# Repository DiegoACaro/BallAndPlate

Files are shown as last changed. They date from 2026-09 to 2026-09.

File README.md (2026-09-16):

# Ball and Plate — Control Systems Comparison

> Experimental Ball and Plate platform for comparing classical, modern, and biologically inspired control strategies.





<p align="center">
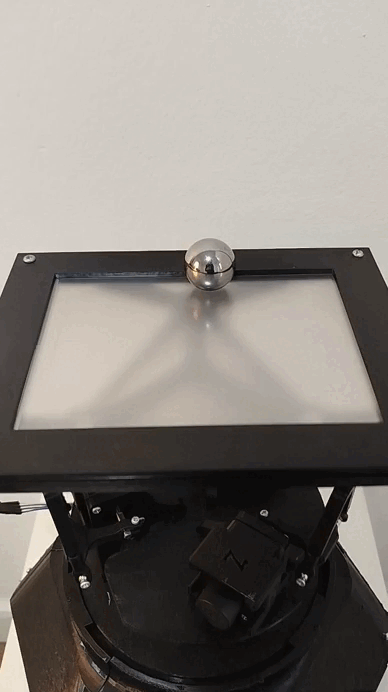
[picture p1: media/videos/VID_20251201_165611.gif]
Ball and Plate platform demo
  
</p>

## Overview

This project presents the design and experimental implementation of a **Ball and Plate system** developed as a platform for studying and comparing different control approaches.

The system consists of a mobile platform whose inclination is controlled to regulate the position of a ball on its surface. Because the plant is nonlinear and inherently unstable, the platform provides a practical testbed for evaluating controller performance under real physical conditions.

The project was developed as an undergraduate Mechatronics Engineering thesis at **Universidad Autónoma de Occidente** in 2025.

The study compares:

- **PID control**
- **Discrete LQR control with integral action**
- **Biologically inspired neural-network-based control**

The experimental evaluation considers parameters such as settling time, overshoot, position regulation, stability, and response to different reference trajectories.

## Project Objectives

The main objective was to design and implement a Ball and Plate system to compare modern control algorithms with biologically inspired neural networks.

The project included:

1. Designing and constructing the physical Ball and Plate platform.
2. Implementing the sensing, processing, actuation, and communication subsystems.
3. Developing a mathematical model of the system.
4. Implementing a classical PID controller.
5. Designing and implementing a discrete LQR controller.
6. Developing a biologically inspired sensoriomotor neural architecture.
7. Experimentally evaluating and comparing the controllers.

## System Architecture

The complete system integrates:

```text
                ┌──────────────────────┐
                │      Ball Position   │
                │        Sensing        │
                └──────────┬───────────┘
                           │
                           ▼
                ┌──────────────────────┐
                │  Embedded Processing │
                │        ESP32         │
                └──────────┬───────────┘
                           │
             ┌─────────────┼─────────────┐
             │             │             │
             ▼             ▼             ▼
          PID            LQR        Neural Control
             │             │             │
             └─────────────┼─────────────┘
                           │
                           ▼
                ┌──────────────────────┐
                │      Actuators       │
                └──────────┬───────────┘
                           │
                           ▼
                ┌──────────────────────┐
                │    Mobile Platform   │
                │     Ball & Plate     │
                └──────────────────────┘
```

## Mechanical Design

The platform was designed as a **3RRS parallel mechanism**, inspired by the kinematic principles of Stewart platforms.

The thesis explicitly treats the system as a simplified parallel mechanism rather than a full six-degree-of-freedom Stewart platform.

The mechanical development included:

- Fixed base
- Mobile platform
- Actuator mounting brackets
- Motor arms
- Passive links
- Spherical joints
- Structural enclosure
- 3D-printed components
- Complete mechanical assembly

The design process included CAD modeling, material selection, manufacturing considerations, and physical assembly.

## Mathematical Modeling

A mathematical model was developed to describe the dynamics of the Ball and Plate system.

The modeling process included:

- Definition of coordinate systems and state variables
- Kinematic relationships
- Kinetic-energy analysis
- Potential-energy analysis
- System equations
- Linearization around the equilibrium point
- Actuator modeling
- Inverse kinematics

The linearized model was subsequently used for the modern control design.

## Control Strategies

### 1. PID Controller

A PID controller was implemented as a classical control baseline.

The proportional, integral, and derivative gains were adjusted heuristically to obtain a stable response suitable for experimental operation.

The PID controller was used as an accessible baseline for evaluating the more advanced approaches.

### 2. Discrete LQR Controller

A discrete Linear Quadratic Regulator was designed using the linearized system model.

The controller incorporates integral action to reduce steady-state error for non-zero references.

The design process included:

- State-space modeling
- System augmentation with an integral state
- Selection of weighting matrices using Bryson's rule
- Zero-Order Hold discretization
- Discrete controller implementation

The experimentally obtained gain parameters reported in the thesis include:

```text
Kp = [0.3717249833, 0.6492662298, 4.7860201182, 3.0881250565]
Ki = -0.0989469993
```

### 3. Biologically Inspired Neural Controller

The project also implements a biologically inspired sensoriomotor controller.

Its architecture is based on concepts inspired by biological visuomotor pathways and sensoriomotor transformations.

The network incorporates:

- Spatial coding
- Auxiliary neural layers
- Internal neuronal dynamics
- Activation conversion
- Modular organization
- Recurrent inhibitory interactions
- Motor neurons

The neural activity changes according to the position and movement of the ball. The auxiliary layers exhibit stronger activation when the ball is far from the center and lower activation as the ball approaches the desired equilibrium.

## Experimental Results

The controllers were experimentally evaluated using the physical Ball and Plate system.

The thesis reports the following measurements for the LQR and biologically inspired neural controllers:

| Controller | Axis | Maximum Position (m) | Overshoot | Settling Time |
|---|---:|---:|---:|---:|
| Neural | X | 0.145754 | 34.89% | 9.829 s |
| Neural | Y | 0.132814 | 36.17% | 9.703 s |
| Discrete LQR | X | 0.166377 | 44.32% | 7.961 s |
| Discrete LQR | Y | 0.121640 | 29.13% | 7.212 s |

The experiments also included reference trajectories with different geometries, including:

- Ellipse
- Square
- Infinity-shaped trajectory

The reported experimental results show that the discrete LQR achieved shorter settling times, while the biologically inspired controller exhibited lower overshoot on the X axis.

### Trajectory Tracking Gallery

For each reference trajectory, the platform's video response is shown alongside the tracked ball trajectory.

| Ellipse | Square | Infinity |
|:---:|:---:|:---:|
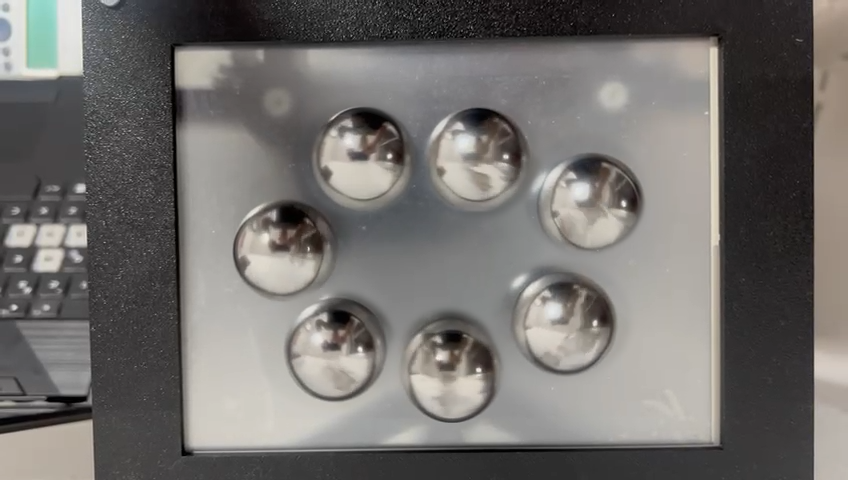
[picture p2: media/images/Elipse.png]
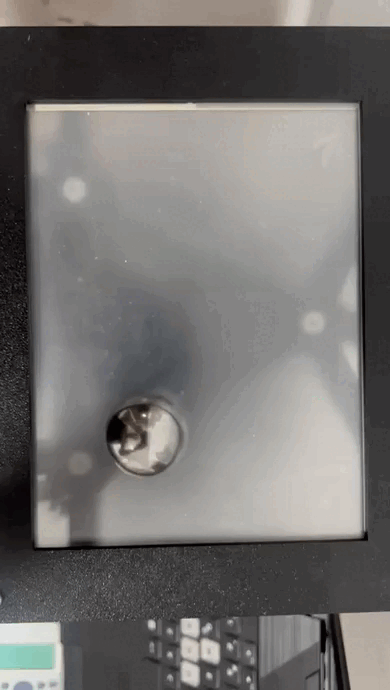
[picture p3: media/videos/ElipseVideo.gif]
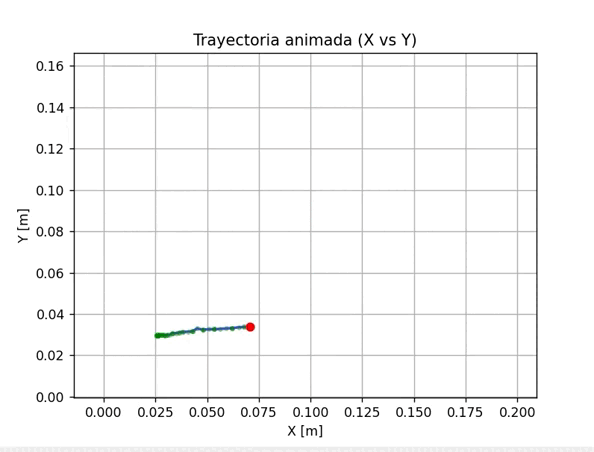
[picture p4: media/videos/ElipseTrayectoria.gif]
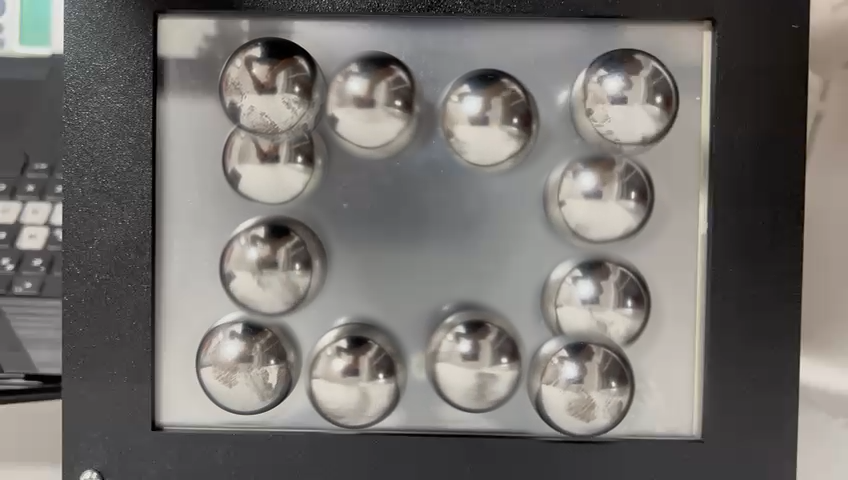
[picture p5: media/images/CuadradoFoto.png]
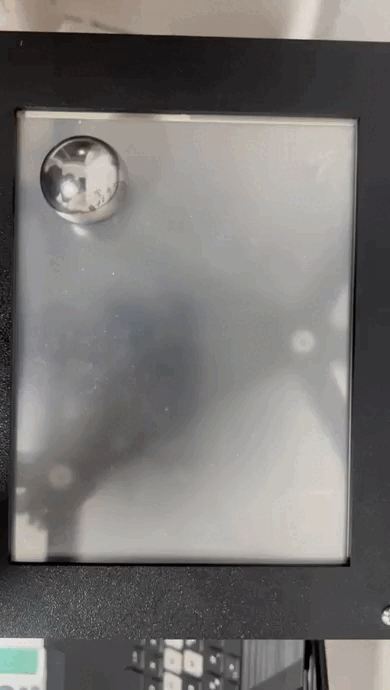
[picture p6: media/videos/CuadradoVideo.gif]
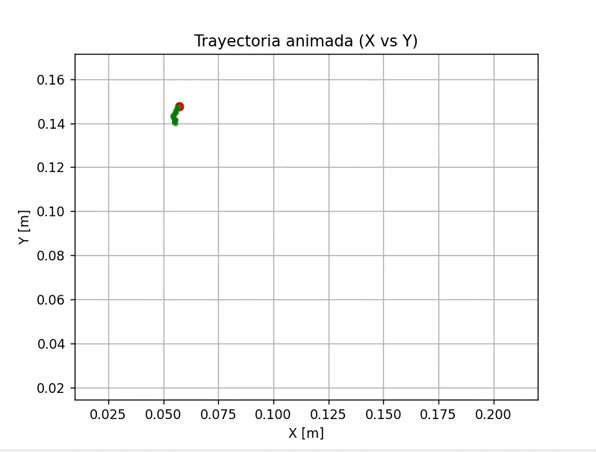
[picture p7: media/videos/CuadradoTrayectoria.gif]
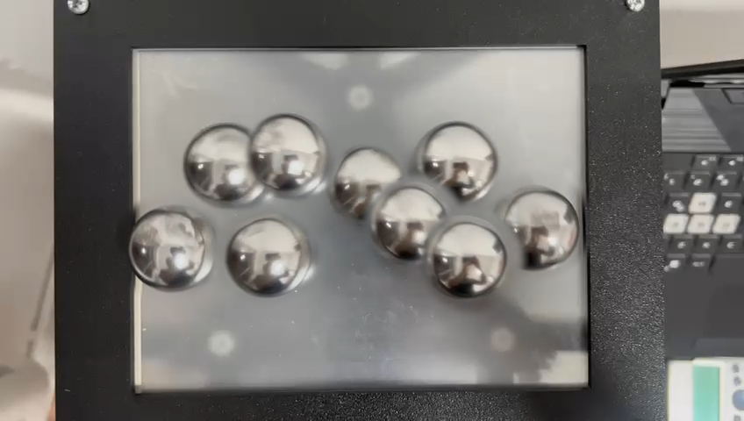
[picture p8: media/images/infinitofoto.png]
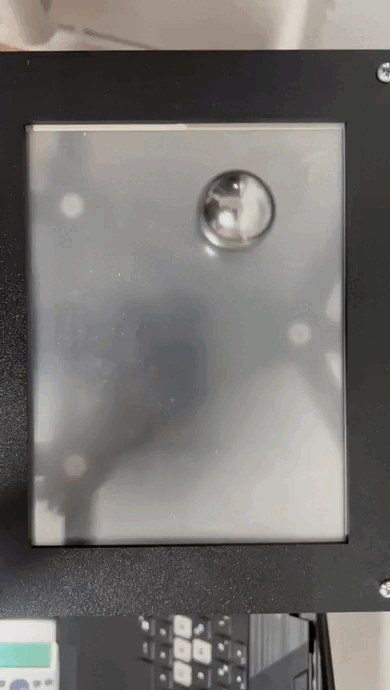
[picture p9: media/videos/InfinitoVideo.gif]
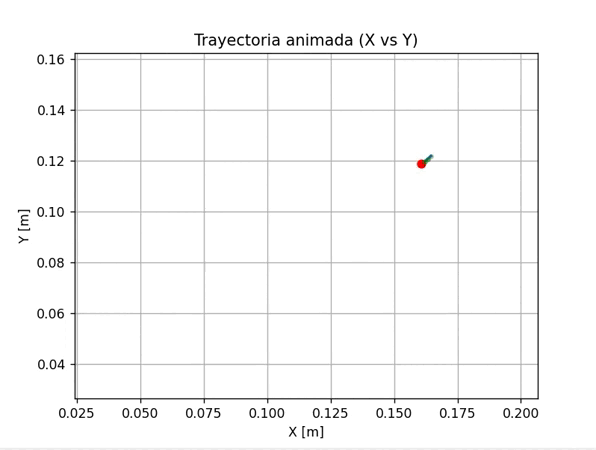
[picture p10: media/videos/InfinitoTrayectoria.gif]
| <br><br> | <br><br> | <br><br> |

*Top: reference setup photo · Middle: platform response video · Bottom: recorded ball trajectory*

### Controller Demonstrations

| Neural Controller | Follower / Tracking Demo |
|:---:|:---:|
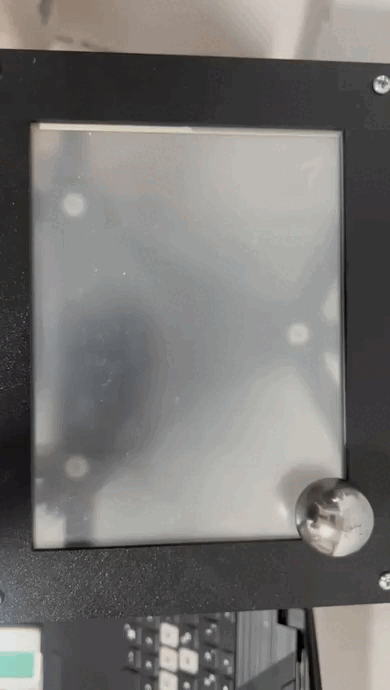
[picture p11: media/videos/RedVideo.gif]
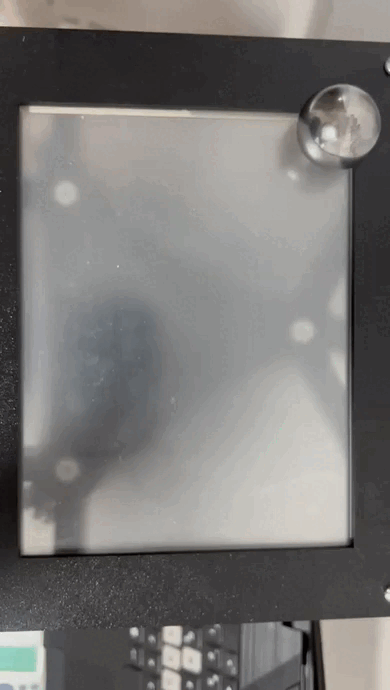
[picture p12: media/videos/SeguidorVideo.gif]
|  |  |

## Technologies

### Control & Modeling

- MATLAB
- State-space modeling
- PID control
- Discrete LQR / LQI
- Linearization
- Inverse kinematics

### Embedded Systems

- ESP32
- Arduino ecosystem
- Real-time control
- Sensor acquisition
- Actuator control
- Digital communication

### Mechanical Design

- SolidWorks
- CAD modeling
- Parallel mechanisms
- 3D-printed components
- Mechanical assembly

### Neural Control

- Biologically inspired neural networks
- Sensoriomotor transformations
- Recurrent inhibition
- Modular neural architectures

## Hardware

The thesis documents the selection and integration of:

- Camera-based ball-position sensing
- ESP32-based processing
- Actuators for platform inclination
- Electronic control hardware
- Mechanical links and spherical joints
- Custom-designed structural components

Component selection was performed through comparative screening matrices considering technical, operational, and economic criteria.

## Communication and Software

The system includes communication between the sensing, processing, control, and actuation subsystems.

The thesis also documents a graphical user interface (GUI) for interaction with the system and visualization of relevant information.

## Repository Structure

```text
ball-and-plate/
│
├── README.md
├── docs/
│   ├── thesis.pdf
│   ├── electronics/
│   └── diagrams/
│
├── cad/
│   ├── parts/
│   └── assembly/
│
├── src/
│
├── modeling/
│   ├── dynamics/
│   └── kinematics/
│
└── media/
    ├── images/
    └── videos/

```

> The structure above is a recommended organization for the repository. It should be adjusted to match the actual files included in the project.

## Key Engineering Topics

This project combines several areas of mechatronics and robotics:

- Control engineering
- State-space systems
- Optimal control
- Nonlinear-system analysis
- Parallel mechanisms
- Robot kinematics
- Embedded systems
- Computer vision
- Neural computation
- CAD and mechanical design
- Experimental validation

## Thesis

**Comparison of Modern Control and Biologically Inspired Neural Networks in the Implementation and Design of a Ball and Plate System**

**Authors:** Diego Alejandro Caro Vaca and Brian Steven Realpe Meneses  
**Program:** Mechatronics Engineering  
**Institution:** Universidad Autónoma de Occidente  
**Year:** 2025

The complete thesis contains the detailed mechanical design, component selection, mathematical modeling, controller design, neural architecture, experimental methodology, and results.

## Project Highlights

- Physical implementation of a Ball and Plate platform.
- 3RRS parallel mechanism.
- Mathematical modeling and linearization.
- Classical PID control.
- Discrete LQR with integral action.
- Biologically inspired sensoriomotor neural control.
- Experimental comparison using settling time and overshoot.
- Reference trajectory tracking.
- Integration of mechanical, electronic, sensing, and control subsystems.

## Authors

**Diego Alejandro Caro Vaca**  
Mechatronics Engineering

**Brian Steven Realpe Meneses**  
Mechatronics Engineering

---

*This repository documents an academic engineering project developed as part of a Mechatronics Engineering thesis.*

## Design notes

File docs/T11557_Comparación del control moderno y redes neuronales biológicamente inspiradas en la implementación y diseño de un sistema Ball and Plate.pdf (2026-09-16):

COMPARACIÓN DEL CONTROL MODERNO Y REDES NEURONALES BIOLÓGICAMENTE INSPIRADAS EN LA IMPLEMENTACIÓN Y DISEÑO DE UN SISTEMA BALL AND PLATE

DIEGO ALEJANDRO CARO VACA
2215332
BRIAN STEVEN REALPE MENESES 2190733

UNIVERSIDAD AUTÓNOMA DE OCCIDENTE FACULTAD DE INGENIERÍA Y CIECIAS BÁSICAS PROGRAMA INGENIERÍA MECATRÓNICA SANTIAGO DE CALI
2025

COMPARACIÓN DEL CONTROL MODERNO Y REDES NEURONALES BIOLÓGICAMENTE INSPIRADAS EN LA IMPLEMENTACIÓN Y DISEÑO DE UN SISTEMA BALL AND PLATE

DIEGO ALEJANDRO CARO VACA
BRIAN STEVEN REALPE MENESES

Proyecto de grado para optar al título de Ingeniero Mecatrónico

Director
JIMMY TOMBE ANDRADE
Ingeniero Eléctrico
Magíster en Ingeniería

UNIVERSIDAD AUTÓNOMA DE OCCIDENTE FACULTAD DE INGENIERÍA Y CIECIAS BÁSICAS PROGRAMA INGENIERÍA MECATRÓNICA SANTIAGO DE CALI
2025

Nota de aceptación:

Aprobado por el Comité de Grado en cumplimiento de los requisitos exigidos
por | la | Universidad | Autónoma | de
Occidente para optar al título de Ingeniero Mecatrónico

DAVID FERNANDO RAMÍREZ MORENO Jurado

Santiago de Cali, 04 de diciembre de 2025

"Este trabajo refleja el valor de la constancia y la perseverancia frente a los desafíos, recordando que el esfuerzo continuo siempre conduce a resultados."
Dedicado a mis padres, Lisbeth Vaca y Diego Alexander Caro, en agradecimiento por su amor incondicional, por enseñarme el valor del esfuerzo y la constancia y por el apoyo que me han brindado a lo largo de mi vida.
A mi hermana, Sofia Caro, por ser mi fuente de inspiración motivación a lo largo de toda mi vida y por ser la razón por la que cada día quiero ser una mejor persona.
Al profesor David Ramírez, por todas las enseñanzas dadas durante mi carrera y por generarme la motivación de siempre apuntar más alto.
A mis amigos, que me han apoyado sin importar qué, y han estado ahí siempre que he necesitado ser aconsejado.
Y a todas las personas que, de alguna u otra forma influyeron de forma positiva en mi camino y me han alentado a seguir adelante.”

Diego Alejandro Caro Vaca

“Dedico este trabajo a mis padres, Luz Meneses Quiñones y Reinel Realpe Velasco, por ser la base de cada uno de mis logros y el mayor ejemplo de esfuerzo y dedicación. Gracias por su amor incondicional, por el sacrificio constante que han hecho para que hoy este sueño se haga realidad, por enseñarme que la perseverancia y el trabajo son el camino hacia cualquier meta.
A mi hermana y compañera de vida, quien ha estado presente en cada instante de esta etapa. Gracias por la confianza, la alegría y cada momento compartido. Tu apoyo es fuente de motivación, espero la culminación de esta etapa sea motivo de orgullo para ti. Al profesor y director de tesis, Jimmy Tombé, a quien admiro y respeto profundamente, por su guía, orientación y confianza durante el desarrollo de este proyecto.
Al profesor y amigo, David Ramírez, por su apoyo, motivación y enseñanzas, que marcaron un antes y un después tanto en mi formación profesional como personal.
A mis seres queridos, aquellos que me acompañaron de cerca y también a quienes ya no están, pero dejaron una huella imborrable en mi vida. A quienes, con su ejemplo desde mi infancia, me inspiraron a ser mejor cada día; a las nuevas personas que llegaron para quedarse y aportan luz en mi vida. Todos, de una u otra forma, hicieron parte de la concreción de este sueño.
A mis compañeros, por compartir jornadas de trabajo, frustraciones y satisfacciones, y por hacer de este camino una experiencia que recordaré siempre con gratitud.”
Brian Steven Realpe Meneses

AGRADECIMIENTOS

Queremos expresar nuestro más sincero agradecimiento a la Universidad Autónoma de Occidente, por ser el espacio donde adquirimos las herramientas, los conocimientos y las experiencias que enriquecieron nuestra formación profesional.

A nuestro director de tesis, Jimmy Tombé Andrade, le expresamos un profundo agradecimiento por su absoluta confianza y por compartir con nosotros sus conocimientos, sus orientaciones y sugerencias para el desarrollo técnico y conceptual de este proyecto.

De igual forma, extendemos nuestro agradecimiento al profesor David Ramírez Moreno, por su constante motivación, por los conocimientos impartidos y por su influencia en nuestro crecimiento académico y personal, impulsándonos a mejorar de manera continua y a superar nuestras propias limitaciones. Su entusiasmo y apoyo fueron determinantes para fortalecer nuestra disciplina y compromiso con la investigación.

A los laboratorios y espacios de la universidad, agradecemos por ser el entorno donde pudimos aplicar y consolidar lo aprendido, convirtiéndose en testigos de nuestro proceso de formación, esfuerzo y evolución profesional.

Finalmente, agradecemos a todas las personas que, de una u otra forma, contribuyeron positivamente al desarrollo de este trabajo, brindándonos su apoyo, consejos y conocimientos que hicieron posible la culminación de esta etapa.

CONTENIDO

pág.

RESUMEN | 15
INTRODUCCIÓN | 16
1. PLANTEAMIENTO DEL PROBLEMA | 17
2. JUSTIFICACIÓN | 19
3. ANTECEDENTES | 20

### 3.1 IMPLEMENTATION OF A BALL AND PLATE CONTROL SYSTEM USING

SLIDING MODE CONTROL | 20

### 3.2 NEURAL NETWORK-BASED PID COMPENSATION FOR NONLINEAR

SYSTEMS: BALL-ON-PLATE EXAMPLE | 21
3.3 BALANCING BALL ON A PLATE: MODELING AND CONTROL | 23
4. OBJETIVOS | 24
4.1 OBJETIVO GENERAL: | 24
4.2 OBJETIVOS ESPECIFICOS | 24
5. MARCO TEÓRICO | 25
5.1 HISTORIA DE LOS MANIPULADORES PARALELOS | 25
5.2 MANIPULADORES PARALELOS | 26
5.2.1 Clasificación de los manipuladores paralelos | 28
5.2.2 Plataforma Stewart | 32
5.2.3 Sistemas no lineales | 33
5.2.4 Sistemas de control | 34
5.2.5 Métodos de diseño de controladores | 35

5.2.6 Control basado en redes neuronales biológicamente inspiradas | 35
5.2.7 Interfaz gráfica de usuario | 39
6. METODOLOGÍA | 40
6.1 DISEÑO E IMPLEMENTACIÓN DEL SISTEMA BALL AND PLATE | 40
6.1.1 Consideraciones cinemáticas del sistema | 40
6.1.2 Requerimientos funcionales y características estructurales | 41
6.2 SELECCIÓN DE COMPONENTES | 46
6.2.1 Sensores | 46
6.2.2 Elementos para el procesamiento | 49
6.3 DISEÑO FÍSICO Y ENSAMBLAJE | 51
6.3.1 Diseño del sistema mecánico y estructural | 51
6.3.2 Selección del material estructural y método de manufactura | 55
6.4 CONSTRUCCIÓN DEL SISTEMA | 58
6.5 DISEÑO ELECTRÓNICO | 58
6.6 GUI | 63
6.7 PROTOCOLOS DE COMUNICACIÓN | 65
7. MODELACIÓN DEL SISTEMA | 67
7.1 FUNDAMENTOS FÍSICOS Y SUPOSICIONES DEL MODELO | 67
7.2 DEFINICIÓN DE VARIABLES Y SISTEMA DE REFERENCIA | 67
7.3 ANÁLISIS DE ENERGÍAS | 69
7.3.1 Energía cinética | 69
7.3.2 Energía potencial | 72
7.3.3 Formulación y simplificación de las ecuaciones del sistema | 72
7.3.4 Representación del sistema linealizado para control | 77

7.4 MODELACIÓN ACTUADOR | 78
7.5 CINEMÁTICA INVERSA | 79
7.5.1 Notación | 80
7.5.2 Descripción matemática | 80
8. MÉTODOS DE CONTROL | 83
8.1 CONTROL CLASICO | 83
8.1.1 PID | 83
8.2 CONTROL MODERNO | 83
8.2.1 Diseño del controlador LQR discreto | 83

### 8.3 CONTROL BASADO EN REDES NEURONALES BIOLÓGICAMENTE

INSPIRADAS | 88
8.3.1 Fundamento cientifico | 88
8.3.2 Estructura y organización de la Red | 90
8.3.3 Dinámica interna y procesamiento neuronal | 91
8.3.4 Capa de conversión y dinámica de Activación | 91
8.3.5 Red modular | 92
9. RESULTADOS | 94
9.1 CONTROLADOR PID | 94
9.2 CONTROLADOR LQR DISCRETO | 94
9.3 CONTROLADOR NEURONAL | 96
9.4 COMPARACIÓN | 97
10. CONCLUSIONES | 99
REFERENCIAS | 100

ANEXOS | 106

LISTA DE FIGURAS

pág.

Figura 1. Concepto de plataforma Stewart con actuadores rotacionales | 20
Figura 2. Curvas de respuesta y desempeño de los controladores | 21
Figura 3. Estructura de control propuesta | 22
Figura 4. Diseño de la red neuronal | 22
Figura 5. Diseño total del sistema ball and plate | 23
Figura 6. Primer mecanismo paralelo | 25
Figura 7. Plataforma de Gough y Stewart | 26
Figura 8. Mecanismo de bucle abierto y bucle cerrado | 27
Figura 9. Arquitecturas de manipuladores paralelos | 27
Figura 10. Manipulador paralelo 3RRR | 28
Figura 11. Plataforma Stewart | 29
Figura 12. Manipulador paralelo Delta | 30
Figura 13. Manipulador paralelo esférico | 30
Figura 14. Estructura de una neurona | 36
Figura 15. Neurona artificial basada en la biología. | 37
Figura 16. Diagrama de bloques del sistema | 42
Figura 17. Caja transparente del sistema | 42
Figura 18. CAD de la base fija | 51
Figura 19. CAD de las escuadras de fijación para los actuadores | 52
Figura 20. CAD del brazo | 52
Figura 21. CAD del eslabón pasivo | 53
Figura 22. Rotulas esféricas | 53

Figura 23. CAD de plataforma móvil | 54
Figura 24. CAD de la carcasa de motor paso a paso | 54
Figura 25. CAD del cuerpo estructural | 55
Figura 26. Ensamble completo | 55
Figura 27. Sistema “Ball and plate” físico | 58
Figura 28. Sistemas de referencia | 68
Figura 29. Definición del vector de posición de la esfera | 70
Figura 30. Energía potencial de la esfera | 72
Figura 31. Diagrama de bloques de un controlador PID | 79
Figura 32. Representación de parámetros para la cinemática inversa | 80
Figura 33. Animat en entorno virtual | 88
Figura 34. Vista de conectividad neuronal del animat | 89
Figura 35. Estructura y conectividad de centros visomotores | 89
Figura 36. Anillo | 90
Figura 37. Red Modular | 93
Figura 38. Circuito sináptico de inhibición recurrente | 93
Figura 39. Respuesta temporal del PID | 94
Figura 40. Respuesta temporal del LQR discreto | 95
Figura 41. Respuesta temporal del control neuronal | 96
Figura 42. Respuesta temporal capa auxiliar eje x | 96
Figura 43. Respuesta temporal capa auxiliar eje y | 97
Figura 44. Dinámica neuronas motoras | 97

LISTA DE TABLAS

pág.

Tabla 1. Resultados antecedentes 2 | 21
Tabla 2. Características del control clásico y el control moderno | 35
Tabla 3. Funciones de activación | 38
Tabla 4. Criterios cinemáticos del sistema | 41
Tabla 5. Necesidades del cliente | 43
Tabla 6. Evaluación necesidades del cliente vs variables técnicas | 44
Tabla 7. Evaluación subsistemas vs métricas | 44
Tabla 8. Matriz de tamizaje – Sensor | 47
Tabla 9. Matriz de tamizaje – Motor | 49
Tabla 10. Matriz de tamizaje – Elementos de procesamiento | 50
Tabla 11. Propiedades físicas de materiales | 56
Tabla 12. Matriz de tamizaje – Material | 56
Tabla 13. Parámetros de impresión por deposición fundida | 57
Tabla 14. Mapeo pines ESO32 WROOM | 59
Tabla 15. Mapeo pines ATmega 2560 | 60
Tabla 16. Componentes electrónicos utilizados en el sistema | 61
Tabla 17. Interfaz Hombre-Máquina | 63
Tabla 18. Información que debe proporcionar el usuario | 63
Tabla 19. Información que el usuario debe ver | 64
Tabla 20. GUI | 64
Tabla 21. Protocolos de comunicación | 65
Tabla 22. Especificaciones del protocolo de comunicación implementado | 66

Tabla 23. Nomenclatura utilizada para la modelación cinemática y
dinámica del sistema | 68
Tabla 24. Respuestas de la capa auxiliar y neuronas R7 y R8 | 91
Tabla 25. Pruebas experimentales | 95
Tabla 26. Resultados de controladores | 98

LISTA DE ANEXOS

pág.

Anexo A. Acoplamiento motor a base fija | 106
Anexo B. Acoplamiento pantalla TFT al cuerpo estructural | 106
Anexo C. Acoplamiento base fija a tapa del cuerpo estructural | 106
Anexo D. Acoplamiento joystick a soporte | 106
Anexo E. Panel de puertos y carga | 107
Anexo F. Plataforma móvil | 107
Anexo G. Unión entre piezas estructurales | 107
Anexo H. Enlace de recursos multimedia: | 107

RESUMEN

El presente documento aborda el diseño e implementación de un sistema “ball and plate”, que consiste en una superficie plana capaz de inclinarse en diferentes ejes — según los grados de libertad que topológicamente posee — para controlar la posición de una esfera ubicada sobre ella. Este sistema se caracteriza por su naturaleza no lineal e inestable, lo que lo convierte en una plataforma ideal para la validación de diferentes técnicas de control.

El interés de este proyecto radica en la comparación de dos enfoques de control, por un lado, los métodos de control moderno, ampliamente estudiados y aplicados en la ingeniería; y por otro lado, el uso de redes neuronales biológicamente inspiradas, alternativa emergente que, de forma simplificada, busca imitar el comportamiento del sistema nervioso para ofrecer soluciones adaptativas y robustas.

El desarrollo de esta investigación surge de la necesidad de contar con estrategias de control que no solo aseguren estabilidad y precisión en entornos controlados, sino que también sean capaces de adaptarse ante perturbaciones y condiciones poco predecibles. Aun cuando los métodos tradicionales han demostrado efectividad se evidencia la presencia de limitaciones frente a dinámicas no lineales. En contraste, las redes neuronales bioinspiradas han mostrado resultados prometedores en el ajuste dinámico de controladores, aunque su aplicación práctica aún requiere mayor exploración.

La implementación de un sistema “ball and plate” como una plataforma experimental permitirá validar de manera práctica ambos enfoques, evaluando métricas de desempeño tales como tiempo de respuesta, estabilidad, precisión y robustez, entre otras.

Palabras clave: Control moderno, Neurocontrol, Manipulador paralelo, Sistemas no lineales, Diseño asistido por computadora, Cinemática inversa.

INTRODUCCIÓN

En la ingeniería, la distinción entre sistemas lineales y no lineales marca un punto de inflexión en el modo de comprender, modelar y regular fenómenos dinámicos del mundo real. Mientras que los sistemas lineales permiten una descripción matemática sencilla, la mayoría de sistemas físicos relevantes —desde el movimiento de un robot manipulador hasta la dinámica de una aeronave — exhiben un comportamiento intrínsecamente no lineal.

Los sistemas no lineales son caracterizados por sus ecuaciones de estado donde existen términos acoplados o dependencias no proporcionales entre variables. En consecuencia, su respuesta no puede predecirse mediante combinaciones simples de entradas, lo que da lugar a fenómenos complejos como múltiples puntos de equilibrio, oscilaciones autoinducidas, bifurcaciones o incluso caos determinista. Para afrontar este tipo de planteamientos surgió el control moderno, un enfoque basado en la representación del sistema en espacio de estados y en el uso de realimentación multivariable. Este paradigma permitió superar las limitaciones de las técnicas clásicas al ofrecer herramientas de optimización, robustez y observabilidad.

Sin embargo, el control moderno sigue dependiendo de la existencia de un modelo matemático preciso. Cuando la dinámica del sistema es altamente incierta, no estacionaria o difícil de modelar las aproximaciones lineales resultan insuficientes. Ante esta situación, la ingeniería contemporánea ha comenzado a adoptar estrategias inspiradas en la naturaleza. Las redes neuronales biológicamente inspiradas representan un intento por emular la capacidad adaptativa, distribuida y autoorganizada del sistema nervioso. Su arquitectura se fundamenta en modelos de neurofisiología donde circuitos sensoriomotores simples permiten coordinar comportamientos complejos como el equilibrio o la locomoción.

En este marco, el sistema “ball and plate” se presenta como un banco de experimental apropiado para la comparación entre paradigmas. Su dinámica no lineal, su inestabilidad inherente y su alta sensibilidad a las perturbaciones lo convierten en un escenario idóneo para evaluar la eficacia del control moderno frente a las redes neuronales biológicamente inspiradas.

### 1. PLANTEAMIENTO DEL PROBLEMA

La teoría de sistemas de control se centra en el análisis y diseño de componentes interactuantes que permitan alcanzar un comportamiento deseado a través del uso de la retroalimentación. Tradicionalmente, la mayor parte de los modelos matemáticos empleados en el diseño de controladores han sido lineales, debido a que ofrecen simplicidad analítica y permiten representar de manera aproximada el comportamiento de muchos sistemas prácticos que sin percatarnos hacen parte nuestra cotidianidad. Sin embargo, el avance tecnológico de nuestra civilización ha impulsado la aparición de problemas cuya dinámica es no lineal en esencia, derivando en el desarrollo de la teoría de sistemas no lineales de control (Sastry, 1999; Van der Schaft, 2017).

Fenómenos propios de sistemas no lineales —como equilibrios múltiples, ciclos límite, bifurcaciones, corrimiento de frecuencias y caos— aparecen en aplicaciones modernas como manipuladores robóticos, sistemas de inyección de combustible, estructuras aeronáuticas y sistemas de transporte automatizado (Isidori, 1990; Van der Schaft, 2017). En este contexto, técnicas como la pasivación por realimentación, la estabilidad entrada– estado (Sontag, 1989) y procedimientos sistemáticos como el backstepping o el forwarding (Krstic et al., 1995) han dotado, significativamente, de herramienta para el análisis de estos sistemas.

El sistema “ball and plate” representa un ejemplo clásico de un sistema no lineal, altamente inestable y sensible a perturbaciones externas, donde la esfera debe mantenerse en equilibrio sobre una superficie capaz de inclinarse en diferentes ejes. Si bien este sistema ha servido como plataforma experimental para validar técnicas tradicionales y modernas de control, las soluciones implementadas muestran limitaciones al enfrentarse a dinámicas impredecibles o condiciones variables. Métodos como el control por modo deslizante (Bang y Leen, 2018) o los enfoques robustos y difusos (Kassem et al., 2015) han demostrado mejoras en estabilidad, aunque persisten problemas como el chattering y la falta de adaptabilidad.

En este panorama, los enfoques basados en redes neuronales biológicamente inspiradas emergen como una alternativa prometedora. Estas estructuras que buscan emular el procesamiento del sistema nervioso (Utkin et al., 2020; Wilson, 1999; Pérez et al., 2018), permiten compensar no linealidades y ajustarse dinámicamente a las condiciones del sistema (Mohammadi y Ryu, 2020; Dong, et al., 2009). Sin embargo, su aplicación práctica en sistemas físicos como el Ball and Plate aún es incipiente y requiere mayor validación experimental.

De esta manera, se identificó una brecha en el conocimiento: aunque existen comparaciones entre métodos tradicionales y modernos, no se ha evaluado si las redes neuronales bioinspiradas pueden superar a los enfoques clásicos en términos de adaptabilidad, robustez y precisión en un mismo sistema experimental.

En consecuencia, surge la pregunta central de este trabajo:

¿Pueden las redes neuronales superar a los métodos tradicionales en términos de adaptabilidad y rendimiento en tiempo real para el sistema bola plato? ¿O siguen siendo los métodos tradicionales superiores en términos de precisión y robustez bajo condiciones controladas para este sistema?

### 2. JUSTIFICACIÓN

El estudio de sistemas dinámicos no lineales como el “ball and plate” conforman una oportunidad para validar estrategias de control en un entorno físico real. A diferencia de las simulaciones, la implementación experimental permite observar fenómenos que surgen de manera natural en la práctica como ruidos, perturbaciones externas y limitaciones de hardware, todo estos son factores que influyen directamente en el desempeño de los controladores (Bang y Lee, 2018). De este modo, el desarrollo de un sistema experimental no solo amplía la comprensión teórica, sino que también facilita la contrastación objetiva entre distintos enfoques de control.

Los métodos de control moderno han logrado demostrar un desempeño sobresaliente en entornos controlados y bien definidos (Kassem et al., 2015). Sin embargo, sus resultados pueden verse condicionados por la necesidad de un amplio conocimiento matemático del sistema y por la dificultad de adaptarse a condiciones variables. Por otro lado, las redes neuronales biológicamente inspiradas han demostrado en simulaciones la capacidad de adaptación y compensación frente a no linealidades (Mohammadi y Ryu, 2020; Chen et al., et al., 2009; Wlodzislaw y Jankowski 2001). Aun así, la validación práctica de estas sigue siendo limitada, por lo que surge la necesidad evaluar su efectividad frente a métodos consolidados dentro de un mismo marco experimental.

La comparación directa entre ambos enfoques en un sistema “ball and plate” permitirá obtener resultados medibles en términos de tiempo de respuesta, estabilidad, precisión, entre otros. Estos indicadores proporcionarán evidencia objetiva sobre las ventajas y limitaciones de cada estrategia de control, contribuyendo tanto al desarrollo de nuevas aplicaciones como a la optimización de las existentes. Además, la generación de métricas comparativas facilitará el análisis de escenarios donde un método podría superar al otro, lo que aporta un valor agregado en la toma de decisiones para aplicaciones en robótica, automatización y enseñanza del control (Fabregas et al., 2017).

### 3. ANTECEDENTES

### 3.1 IMPLEMENTATION OF A BALL AND PLATE CONTROL SYSTEM USING SLIDING

MODE CONTROL

El trabajo publicado por Bang y Lee (2018), propone la implementación de un sistema de control de “ball and plate” utilizando control por modo deslizante (Sliding mode control, SMC) con la finalidad de la creación de un kit educativo eficiente, rentable y pedagógicamente superior.

El desarrollo metodológico comprendió tanto el diseño mecánico y electrónico como el modelado y control del sistema. La estructura se basó en una plataforma “Stewart” con seis actuadores rotativos en conjunto a 12 articulaciones esféricas, controlados mediante una placa Núcleo-32 con unidad de punto flotante (FPU). La medición de la posición se realizó mediante un panel táctil resistivo, sustituyendo la tradicional cámara de visión con el fin de reducir la latencia e incrementar la frecuencia de muestreo (1 kHz). El controlador de panel táctil ADS7846E, conectado por protocolo SPI, permitió obtener coordenadas (x, y, z).

Figura 1.
Concepto de plataforma Stewart con actuadores rotacionales

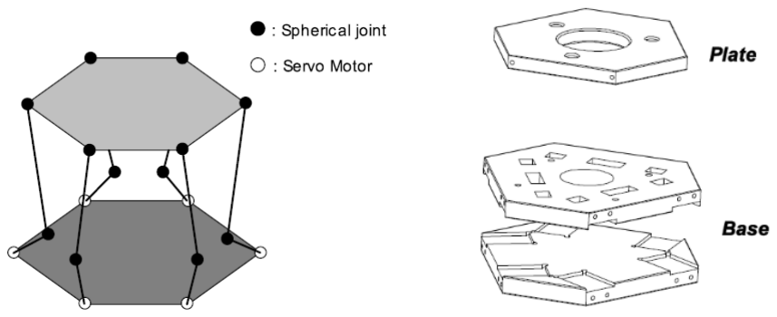
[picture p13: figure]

Nota. Tomado de: “Implementation of a Ball and Plate Control System Using Sliding Mode Control”, por; H., Bang, y Y. S., Lee. 2018. IEEE Access, 6, 32401–32408. https://doi.org/10.1109/ACCESS.2018.2838544

El modelado matemático del sistema se efectuó bajo suposiciones de pequeños ángulos y desprecio de fuerzas centrífugas, formulando la cinemática inversa de la plataforma para determinar los ángulos de cada actuador según la posición deseada de la placa. Posteriormente, se diseñó el controlador por modo deslizante (SMC) incluyendo un término integral del error (modelo aumentado) para mejorar la respuesta del sistema. Para mitigar el problema del chattering, se sustituyó la función signum por una función sigmoidea suavizada, y la estabilidad del controlador se verificó mediante el criterio de Lyapunov.

Figura 2.
Curvas de respuesta y desempeño de los controladores

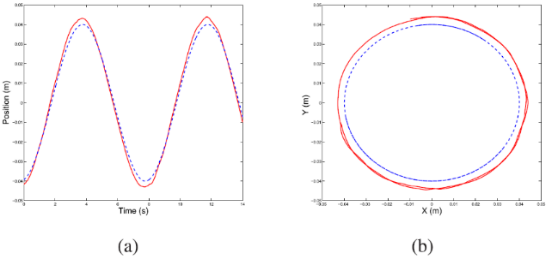
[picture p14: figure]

Nota. Tomado de: “Implementation of a Ball and Plate Control System Using Sliding Mode Control”, por; H., Bang, y Y. S., Lee. 2018. IEEE Access, 6, 32401–32408. https://doi.org/10.1109/ACCESS.2018.2838544

Se comparó el rendimiento de seguimiento de trayectorias circulares (radio de 4 cm) utilizando SMC y control LQ.

Tabla 1.
Resultados antecedentes 2
Controlador | Período (segundos) | Error Máximo (mm)
SMC | 8 | 2 mm
SMC | 4 | 4 mm
LQ Control | 8 | 5 mm
LQ Control | 4 | 12 mm

Los experimentos demostraron que el sistema está bien construido con el método propuesto y puede aplicarse para el estudio de varios controladores. El sistema propuesto es rentable, fácil de construir, tiene un buen rendimiento de control y ocupa un espacio pequeño.

### 3.2 NEURAL NETWORK-BASED PID COMPENSATION FOR NONLINEAR SYSTEMS:

BALL-ON-PLATE EXAMPLE

El trabajo publicado por Mohammadi y Ryu (2020), propone una estrategia de control híbrido basada en la compensación dinámica mediante redes neuronales aplicadas a un sistema ball and plate. Su objetivo principal fue reducir los errores de modelado y de estado estacionario presentes en controladores lineales, combinando un controlador clásico lineal con un compensador PID adaptativo ajustado en tiempo real por una red neuronal.

La metodología consistió en diseñar un esquema de control paralelo formado por un controlador lineal base mediante la linealización por retroalimentación de entrada-salida aproximada (AFL) y un compensador neuronal que modifica dinámicamente las ganancias Kp, Ki y Kd a partir del error, su integral y su derivada.

Figura 3.
Estructura de control propuesta

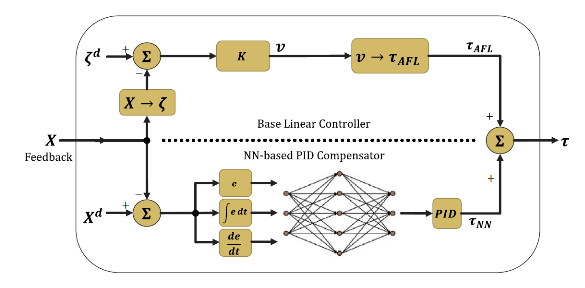
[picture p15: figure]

Nota. Tomado de: “Neural network-based PID compensation for nonlinear systems: ball-on-plate example”, por; A., Mohammadi, y J. C., Ryu. 2020. International Journal of Dynamics and Control, 8(1), 178–188. https://doi.org/10.1007/s40435-018-0480-5

La red neuronal —con tres entradas, una capa oculta de cinco neuronas y una capa de salida de tres neuronas— fue entrenada mediante retropropagación y validada en un sistema físico que integraba visión por computadora con una cámara USB a 120 Hz y procesamiento con OpenCV.

Figura 4.
Diseño de la red neuronal

Nota. Tomado de: “Neural network-based PID compensation for nonlinear systems: ball-on-plate example”, por; A., Mohammadi, y J. C., Ryu. 2020. International Journal of Dynamics and Control, 8(1), 178–188. https://doi.org/10.1007/s40435-018-0480-5

Los resultados de simulación y experimentales demostraron que el controlador propuesto (AFLNN) superó al AFL clásico tanto en estabilización como en seguimiento de trayectorias circulares, reduciendo el error RMS de 8.4 mm a 0.6 mm en simulación, y el error experimental de 0.0115 m a 0.0077 m.

### 3.3 BALANCING BALL ON A PLATE: MODELING AND CONTROL

El trabajo publicado por Lakzaei (2020), tuvo como objetivo el desarrollo de un sistema de seguimiento y estabilización en tiempo real para un sistema de “ball and plate”, articulado sobre una plataforma Stewart de tres grados de libertad (3 DOF).

Figura 5.
Diseño total del sistema ball and plate

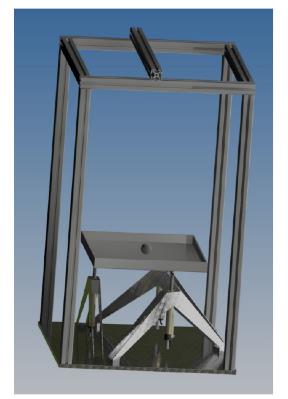
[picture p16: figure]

Nota. Tomado de: “Balancing ball on a plate - Final Report”, por; E., Lakzaei. 2020. Eindhoven University of Technology. https://doi.org/10.13140/RG.2.2.26127.00161

El trabajo se desarrolló de manera estructurada: primero se derivó un modelo dinámico completo mediante las ecuaciones de Euler–Lagrange, considerando condiciones idealizadas (sin deslizamiento ni fricción apreciable) y aplicando una linealización bajo el supuesto de pequeños ángulos para desacoplar los movimientos en los ejes X y Y. Posteriormente, se implementó un esquema de control en cascada, compuesto por un lazo interno para los actuadores —basado en un modelo de primer orden— y un lazo externo encargado del control de la posición de la bola, diseñado mediante el método del lugar de las raíces y posteriormente discretizado debido a la frecuencia de muestreo limitada (10 Hz) de la cámara empleada.

El sistema logró seguir trayectorias circulares e incluso en forma de infinito, cumpliendo con los requisitos de estabilidad y sobre impulso. Se observó un error menor entre las mediciones experimentales y las simuladas (por ejemplo, una aceleración promedio de 2.59 m/s² frente a 2.2 m/s² simulada), confirmando la validez del modelo.

### 4. OBJETIVOS

### 4.1 OBJETIVO GENERAL:

Diseñar un sistema “ball and plate” para realizar comparaciones entre algoritmos de control moderno y redes neuronales biológicamente inspiradas.

### 4.2 OBJETIVOS ESPECIFICOS

- Obtener las especificaciones de diseño del sistema y realizar un prototipo funcional.
- Implementar el diseño físico del sistema “ball and plate”.
- Diseñar un controlador basado en métodos de control moderno y realizar un diseño de una red neuronal (bioinspirada) para controlar el sistema.
- Implementar el controlador y la red para evaluar el desempeño de ambos métodos en términos de estabilidad, tiempo de respuesta, robustez ante perturbaciones y precisión de control.

### 5. MARCO TEÓRICO

### 5.1 HISTORIA DE LOS MANIPULADORES PARALELOS

Los manipuladores paralelos surgieron como una alternativa a los manipuladores seriales, buscando mejorar la rigidez, la precisión y la capacidad de carga. Su evolución muestra un proceso que parte desde sus primeras concepciones teóricas hasta convertirse en elementos clave dentro de lo que hoy es concebido como la sociedad humana trascendiendo barreras en diferentes industrias (Aracil et al., 2006).

Los antecedentes más tempranos se remontan a 1931, donde Gwinnett patentó un sistema para el movimiento de asientos en teatros, con el objetivo de ofrecer una experiencia más realista. Aunque este diseño nunca fue llevado a la realidad, representó el primer intento documentado de implementar un mecanismo paralelo con movilidad controlada (Duarte Barón y Borrás Pinilla, 2016).

Figura 6.
Primer mecanismo paralelo

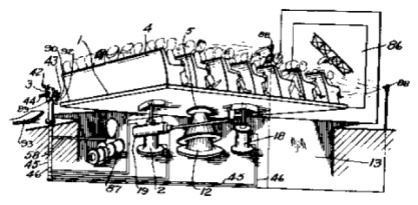
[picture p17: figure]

Nota. Tomado de: “Robots Paralelos: Máquinas con un Pasado para una Robótica del Futuro.”, por; R., Aracil; R. J., Saltarén; J. M., Sabater; Ó., Reinoso. 2006. Revista
Iberoamericana | de | Automática | e | Informática | industrial, | 16-18.
https://polipapers.upv.es/index.php/RIAI/article/view/8105.

En 1947, Gough diseñó y construyó en la empresa Dunlop un mecanismo de 6 grados de libertad (GDL) para ensayos de neumáticos, considerado el primer manipulador paralelo funcional. A partir de este hito, comenzaron a consolidarse los fundamentos de las plataformas paralelas modernas. Años más tarde, D. Stewart propuso en 1965 un simulador de vuelo basado en un hexápodo paralelo, lo que popularizó este tipo de mecanismos bajo el nombre de Plataforma Gough–Stewart (Aracil et al., 2006; Duarte Barón y Borrás Pinilla, 2016; Gough y Whitehall, 1962).

Figura 7.
Plataforma de Gough y Stewart

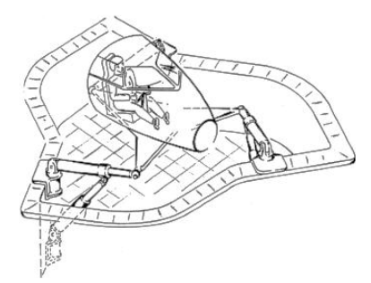
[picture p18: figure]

Nota. Tomado de: “Robots Paralelos: Máquinas con un Pasado para una Robótica del Futuro.”, por; R., Aracil; R. J., Saltarén; J. M., Sabater; Ó., Reinoso. 2006. Revista
Iberoamericana | de | Automática | e | Informática | industrial, | 16-18.
https://polipapers.upv.es/index.php/RIAI/article/view/8105.

Para continuar con la cronología, según Duarte Barón y Borrás Pinilla (2016), indica que “el interés de la industria automotriz por los simuladores impulsó nuevas variantes. Volkswagen desarrolló a inicios de los años setenta el primer simulador de conducción de 3 GDL (Slob, s.f) ; más adelante, Ford introdujo el Virttex con 6 GDL; y la Universidad de Iowa presentó el simulador NADS, que alcanzaba 9 GDL. Otras compañías, como Renault, incorporaron plataformas de 6 GDL con bases móviles en XY (Blana, 1996), mientras que Toyota construyó un diseño similar al NADS, pero con dimensiones ampliadas (De Winter et al., 2007)”.

### 5.2 MANIPULADORES PARALELOS

Los manipuladores paralelos, también denominados robots paralelos, son mecanismos en los cuales una plataforma móvil se conecta a una base fija mediante varias cadenas cinemáticas cerradas — sistema mecánico donde el último eslabón está conectado, directa o indirectamente, al primer eslabón o base estructural — que con regularidad están conformadas por eslabones pasivos. A diferencia de los manipuladores seriales donde los eslabones están dispuestos en serie de tal modo que no existe una regresión hacia el primer eslabón (Uchiyama, 1993), en los paralelos la carga y los esfuerzos se distribuyen entre todas las ramas otorgando ventajas sobre algunas propiedades como la rigidez estructural, la capacidad de carga, la precisión en sus movimientos, entre otros. (Duarte Barón y Borrás Pinilla, 2016). La figura 8 ejemplifica los mecanismos de bucle abierto y cerrado (Manipulador serie y manipulador paralelo, respectivamente).

Figura 8.
Mecanismo de bucle abierto y bucle cerrado

Nota. Tomado de: “Structures and characteristics of parallel manipulators”, por; M.,
Uchiyama. | 1993. | Advanced | Robotics, | 8(6), | 545–557.
https://doi.org/10.1163/156855394X00248

En su configuración más común, el número de brazos coincide con el número de grados de libertad (GDL) de la plataforma. Los actuadores pueden ser eléctricos, hidráulicos o neumáticos y su disposición determina la movilidad del sistema (traslacional, rotacional o una combinación de ambas). Cuando todas las cadenas cinemáticas presentan la misma estructura, composición y longitud se habla de manipuladores simétricos, en caso contrario, se clasifican como asimétricos. Todas estas características — arquitectura topológica, tipo de movimiento, GDL, geometría — determina la configuración de manipulador.

Figura 9.
Arquitecturas de manipuladores paralelos

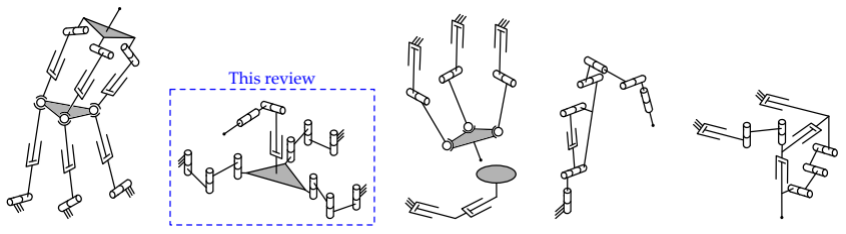
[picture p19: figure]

Nota. Tomado de: “Parallel–serial robotic manipulators: A review of architectures, applications, and methods of design and analysis”, por; A., Antonov. 2024. Machines, 12(11), 10811. https://doi.org/10.3390/machines12110811”

### 5.2.1 Clasificación de los manipuladores paralelos

Existen múltiples formas de clasificar los manipuladores paralelos, dependiendo de los criterios de análisis y diseño con los cuales fueron concebidos.

### 5.2.1.1 Según la movilidad

- Manipuladores paralelos planares

Los manipuladores paralelos planares son aquellos cuya movilidad se restringe a un plano bidimensional. En este tipo de mecanismos, la plataforma móvil puede realizar traslaciones en dos direcciones (X, Y) y, en algunos casos, una rotación alrededor de un eje perpendicular al plano. En esta configuración los actuadores son ubicados en la articulación que conecta el eslabón activo con la base fija de cada cadena cinemática.

- Ejemplo: El manipulador paralelo 3RRR permite hasta 3 grados de libertad en un plano (dos traslaciones y una rotación).

Figura 10.
Manipulador paralelo 3RRR

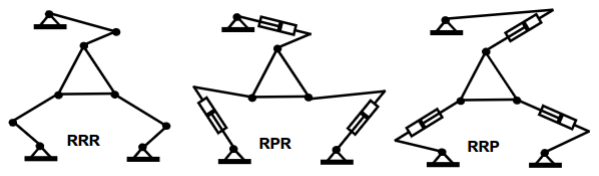
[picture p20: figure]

Nota. Tomado de: “Robots Paralelos: Máquinas con un Pasado para una Robótica del Futuro.”, por; R., Aracil; R. J., Saltarén; J. M., Sabater; Ó., Reinoso. 2006. Revista
Iberoamericana | de | Automática | e | Informática | industrial, | 16-18.
https://polipapers.upv.es/index.php/RIAI/article/view/8105.
- Manipuladores paralelos espaciales

Los manipuladores paralelos espaciales se caracterizan por permitir movimientos tridimensionales completos al combinar traslaciones y rotaciones en los tres ejes del espacio (X, Y, Z) y hasta tres rotaciones (Pitch α, Roll β, Yaw γ) esta capacidad de movimiento es un requisito para denominarse espaciales.

- Ejemplo: La Plataforma Stewart es un manipulador paralelo de 6 GDL que ha sido usado en numerosas aplicaciones tales como: la simulación de vuelo, manufactura, experimentación académica, entre otros (Aracil et al., 2006).

Figura 11.
Plataforma Stewart

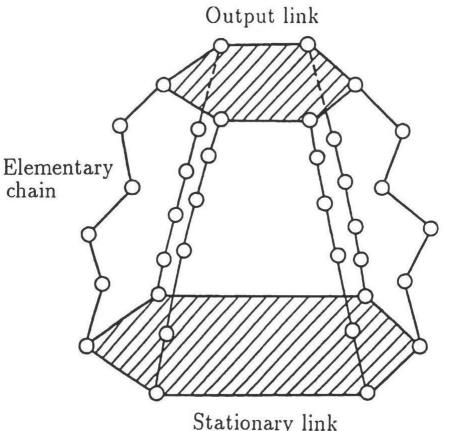
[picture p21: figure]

Nota. Tomado de: “Structures and characteristics of parallel manipulators”, por; M.,
Uchiyama. | 1993. | Advanced | Robotics, | 8(6), | 545–557.
https://doi.org/10.1163/156855394X00248

### 5.2.1.2 Según el tipo de movimiento de la plataforma móvil

- Manipuladores paralelos traslacionales

Estos manipuladores están diseñados para que la plataforma móvil se desplace únicamente en movimientos lineales a lo largo de los ejes espaciales (x, y, z), sin generar rotaciones, es decir, movimientos de traslación pura (Antonov, 2024; Di Gregorio, 2020). Su estructura se centra en mantener la orientación fija de la plataforma mientras se controla su posición.

- Ejemplo: El manipulador Delta, caracterizado por sus tres brazos idénticos conectados a la plataforma mediante articulaciones esféricas.

Figura 12.
Manipulador paralelo Delta

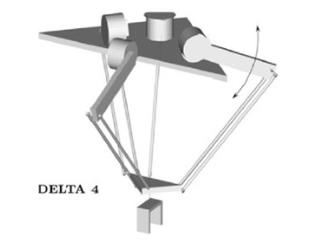
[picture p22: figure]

Nota. Tomado de: “Generalidades de robots paralelos.”, por; K., Duarte Barón, y C.,
Borrás | Pinilla. | 2016. | Visión | electrónica, | 10(1), | 102–112.
doi:https://doi.org/10.14483/22484728.11711
- Manipuladores paralelos esféricos

Estos manipuladores permiten a la plataforma móvil ejecutar únicamente rotaciones alrededor de un punto fijo, similar al movimiento de una rótula. De este modo, el efector final puede orientarse en diferentes direcciones sin modificar su posición en el espacio.

- Ejemplo: Configuraciones de 3 GDL con brazos dispuestos para generar inclinaciones en ángulos específicos, empleados en simuladores de orientación o en sistemas de posicionamiento óptico.

Figura 13.
Manipulador paralelo esférico

Nota. Tomado de: “Modelling of a special class of spherical parallel manipulators with Euler parameters”, por; S., Bai; M. R., Hansen; T. O., Andersen. 2009. Robotica, 27(2), 161-170. doi:https://doi.org/10.1017/S0263574708004402

- Manipuladores paralelos mixtos

En esta categoría se agrupan aquellos manipuladores que combinan movimientos traslacionales y rotacionales, llegando en su forma más completa a ofrecer los 6 GDL clásicos (tres traslaciones y tres rotaciones).

- Ejemplo: La plataforma Stewart, que integra seis actuadores dispuestos simétricamente para ofrecer tanto traslaciones como rotaciones.

### 5.2.1.3 Según la arquitectura de sus cadenas cinemáticas

- Manipuladores paralelos simétricos

Se consideran simétricos aquellos manipuladores en los que todas sus cadenas cinemáticas poseen la misma configuración estructural y funcional. Para que un mecanismo cumpla con esta condición, deben verificarse las siguientes características (Uchiyama, 1993; Huang y Li, 2002):

- El número de brazos es igual al número de grados de libertad (GDL) de la plataforma móvil.
- El tipo y número de uniones en cada brazo está dispuesto de forma idéntica.
- La ubicación de los actuadores es la misma en todas las cadenas.
- Manipuladores paralelos asimétricos

Se denominan asimétricos cuando al menos una de las condiciones anteriores no se cumple. Esto significa que sus brazos pueden diferir en longitud, número de eslabones, disposición de articulaciones o ubicación de actuadores. Este tipo de configuraciones surge principalmente cuando se busca optimizar el espacio de trabajo o adaptar el mecanismo a tareas específicas que no requieren movilidad uniforme en todos los ejes.

### 5.2.1.4 Según el número de grados de libertad (GDL)

Los robots paralelos pueden configurarse desde 2 GDL (mecanismos planares sencillos) hasta 6 GDL (plataformas espaciales completas). Esta característica define el número mínimo de coordenadas generalizadas necesarias en la determinación de posición y orientación. El planteamiento de Grübler se expresa en la siguiente expresión:

F = 6(E − 1) − ∑(6 − f)Pf

f=1

(1)

Donde:

- E es el numero total de links
- Pf es el numero total de joints que tiene f grados de libertad

### 5.2.2 Plataforma Stewart

Como fue mencionado, un manipulador paralelo se caracteriza por estar compuesto por al menos dos cadenas cinemáticas cerradas, partiendo de una base estática o fija que convergen en una plataforma móvil que actúa como efector final (Aracil et al., 2006). Aunque es redundante, es necesario traer a colación este concepto dado a que es fundamental para comprender la plataforma Stewart, denominada una de las configuraciones más comunes de este tipo de sistemas, la cual se constituye como el referente básico en el presente desarrollo (Sevillano Gainza, 2014).

Para la década de 1960, D. Stewart propuso un mecanismo paralelo de seis grados de libertad (6 GDL) diseñado para de generar movimientos en el espacio, de este modo fue dotado con la capacidad de controlar activamente 3 movimientos de traslación (X, Y, Z) y 3 de rotación (Pitch α, Roll β, Yaw γ). Por lo tanto, la plataforma Stewart, en su forma más típica, se reconoce como un diseño orientado al control de posición y movimiento.

En este punto es necesario precisar que, aunque comparte fundamentos conceptuales, el sistema “ball and plate” no puede ser considerado como una plataforma Stewart, ya que no dispone de los seis grados de libertad que esta ofrece. No obstante, puede afirmarse que este sistema constituye una aproximación inspirada en la cinemática de la Stewart, es decir, es una versión simplificada que conserva la esencia del control de equilibrio mediante la inclinación de una superficie (Leal, 2018).

### 5.2.3 Sistemas no lineales

La evolución constante de la sociedad humana, ha traído consigo innumerables desarrollos que, por su naturaleza, no pueden representarse adecuadamente mediante modelos lineales. Estos últimos, aunque han sido utilizados de manera sistemática para describir y modelar fenómenos físicos, económicos, sociales y de cualquier otra índole, presentan limitaciones frente a dinámicas intrínsecamente complejas. De este modo, la teoría ha comprobado que los sistemas no lineales ofrecen aproximaciones más realistas a dinámicas complejas (Gutiérrez, 1998). Es necesario tener presente que un modelo constituye una representación simplificada de un sistema, como fue mencionado anteriormente, con regularidad los modelos matemáticos utilizados son lineales ya que logran representar con precisión relativa el comportamiento de una gama amplia de aplicaciones cotidianas. Sin embargo, en la actualidad el avance de la tecnología enfrenta un mayor de los problemas esencialmente no lineales. Matemáticamente, los sistemas no lineales pueden ser representados del siguiente modo (López Pacheco, 2017; Blanke et al., 2016):

ẋ = f(x, u,t) | (2)
y = ℎ(x, u,t) | (3)
- t es el tiempo
- f es un conjunto de n funciones escalares
- ℎ es un conjunto de q funciones escalares
- x es el vector de estados
- u es el vector de entradas
- y el vector de salidas

Siguiendo a Khalil (1995), es posible destacar varias propiedades distintivas de los sistemas no lineales:

- Tiempo de escape finito: En un sistema lineal inestable, las variables de estado tienden al infinito solo cuando el tiempo avanza indefinidamente.
- Múltiples puntos de equilibrio: Un sistema no lineal puede presentar varios estados de equilibrio independientes. El estado final al que converge el sistema depende de la condición inicial, lo que abre la posibilidad de tener diferentes puntos de operación estables o inestables.

- Ciclos límite: Los sistemas no lineales pueden presentar oscilaciones estables con amplitud y frecuencia constantes, independientemente de las condiciones iniciales.
- Oscilaciones armónicas, subarmónicas o casi-periódicas: Ante una excitación periódica, los sistemas no lineales pueden generar respuestas a frecuencias que son múltiplos o submúltiplos de la señal de entrada, e incluso combinaciones de frecuencias no relacionadas entre sí, dando lugar a oscilaciones casi-periódicas.
- Caos: Este fenómeno, se caracteriza por la extrema sensibilidad a las condiciones iniciales, lo que produce trayectorias aparentemente aleatorias a pesar de que el sistema sea determinista.
- Múltiples modos de comportamiento: Un mismo sistema no lineal puede exhibir más de un modo dinámico. Por ejemplo, puede presentar simultáneamente varios ciclos límite, o bajo una entrada periódica variar entre respuestas armónicas, subarmónicas o caóticas.

La relevancia en la mención de estas características se refleja en la naturaleza del sistema propuesto en este desarrollo. En primer lugar, sus ecuaciones dinámicas incluyen funciones trigonométricas asociadas al movimiento de la esfera en conjunto a los ángulos de inclinación que introducen no linealidades de manera natural. En segundo lugar, el equilibrio en el centro de la plataforma móvil es inherentemente inestable dado a que pequeñas perturbaciones, como una ligera inclinación o una mínima variación en la posición de la esfera, tienden a amplificarse. Por último, el sistema presenta acoplamiento entre variables, conceptualmente los movimientos en los ejes (X, Y) pueden analizarse por separado en un modelo simplificado, en la práctica ambos influyen mutuamente en la trayectoria de la esfera.

### 5.2.4 Sistemas de control

Un sistema dinámico se caracteriza por responder a acciones externas denominadas variables de entrada, produciendo como consecuencia unas variables de salida. Dentro de este marco, las entradas se clasifican en variables de control que pueden manipularse, y perturbaciones, que son influencias externas no controlables (Chen y Patton, 2012; Ding, 2008).

A partir de esta noción surge el concepto de sistema de control, definido como un conjunto de elementos interrelacionados cuyo propósito es regular el comportamiento de un sistema, asegurando que las variables de salida se mantengan próximas a un valor de referencia. Para cumplir con este objetivo, un sistema de control ideal debe garantizar estabilidad y robustez frente a perturbaciones, operar de manera eficiente evitando acciones de control abruptas, y ser factible de implementar en tiempo real.

### 5.2.5 Métodos de diseño de controladores

La consigna de la evolución de la tecnología mencionada anteriormente, no es indiferente con los métodos de diseño de controladores pues mientras en sus orígenes donde predominaban implementaciones analógicas orientadas a sistemas de una sola variable (SISO), el desarrollo de la de herramientas de simulación como Matlab ha potenciado escenarios de investigación con la disposición de entornos digitales y multivariables (MIMO). Es así que en la tabla 2 se presenta una diferenciación sintetizada de lo es llamado control tradicional con el control moderno (Dorf y Bishop, 2022; Patton et al., 2000).

Tabla 2.
Características del control clásico y el control moderno
Características | Control clásico | Control moderno
Base teórica | Función de transferencia y análisis en el dominio de Laplace o frecuencia. | Espacio de estados, análisis vectorial- matricial en el dominio del tiempo.
Representación del sistema | Función de Transferencia (un cociente de
polinomios).
| | Vector de Estado (x(t)) y matrices de estado
(A, B, C, D).
Tipo de sistemas | Principalmente sistemas lineales, invariantes en el tiempo, de una entrada y una salida (SISO). | Sistemas lineales y no lineales, variantes en el tiempo, con múltiples entradas y salidas

(MIMO).
Métodos de análisis | Lugar Geométrico de las Raíces, Criterio de Routh-Hurwitz, PID, Diagramas de Bode, Diagramas de Nyquist, etc. | Asignación de polos por realimentación de estado, Observadores de Estado, Filtro de Kalman, LQR, entre otros.
Aplicaciones típicas | Control de velocidad en motores, regulación de temperatura, sistemas simples de retroalimentación. | Robótica, aeronáutica, vehículos autónomos, energías renovables, procesos industriales complejos.

### 5.2.6 Control basado en redes neuronales biológicamente inspiradas

Es ineludible reconocer la naturaleza como la matriz original de la ingeniería, esta puede apreciarse — metafóricamente — como un laboratorio de vastas proporciones cuya producción ha resultado en la biodiversidad y arquitectura de la vida. La capacidad adaptativa de los organismos vivos — resultado de millones de años de evolución — ha sido inspiración para la humanidad en el diseño de soluciones y en la búsqueda de sistemas que respondan de manera flexible a entornos cambiantes. El imperativo de la supervivencia demanda una respuesta continua a los estímulos de nuestro entorno inherentemente correspondientes a la capacidad de adaptación. En este contexto, el sistema nervioso es la estructura biológica más sofisticada que dota a los organismos biológicos con la capacidad de responder a estímulos externos, siendo la neurona, la unidad mínima responsable de la transmisión y el procesamiento de estas señales.

Los modelos neuronales surgen como una abstracción matemática de estos sistemas biológicos. El primer modelo fue concebido por McCulloch y Pitts (1943), quienes demostraron que la actividad neuronal podía representarse mediante lógica proposicional. Su trabajo, “A Logical Calculus of Ideas Immanent in Nervous Activity”, sentó las bases teóricas para vincular los procesos neuronales con el razonamiento lógico, postulando que el pensamiento podía entenderse como un cálculo ejecutado sobre redes de neuronas interconectadas.

En la actualidad, la literatura demuestra la evolución de las redes neuronales hacia dos vertientes, los modelos artificiales, orientados a resolver problemas de clasificación, predicción o control mediante algoritmos de aprendizaje automático y los modelos biológicamente inspirados, centrados en emular la organización y dinámica de los sistemas nerviosos reales (López Pacheco, 2017). Nuestro enfoque parte de los modelos biológicamente inspirados que apuntan a la neurociencia computacional, así como el propuesto por Wilson (1999), que describe la dinámica de la actividad media de poblaciones de neuronas.

### 5.2.6.1 Neurona Biológica

La neurona es la unidad estructural y funcional fundamental del sistema nervioso, especializada en recibir, procesar y transmitir información a través de señales electroquímicas. Morfológicamente, consta de tres partes principales: el soma o cuerpo celular, que contiene el núcleo y la maquinaria metabólica; las dendritas, que son ramificaciones cortas que actúan como receptores primarios de la señal de otras neuronas; y el axón, una prolongación larga que conduce la señal (impulso nervioso) desde el soma hacia otras neuronas, músculos o glándulas, finalizando en los terminales sinápticos.

Figura 14.
Estructura de una neurona

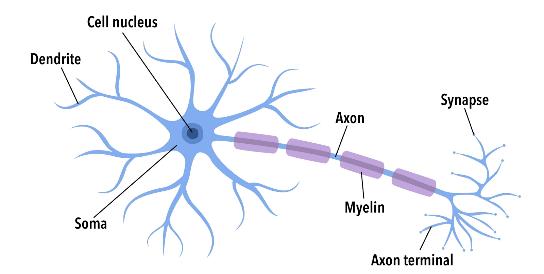
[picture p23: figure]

### 5.2.6.2 Modelo computacional de una neurona

El modelo computacional de una neurona constituye una representación matemática simplificada que busca reproducir el comportamiento de una neurona biológica. Según Ramírez Moreno y Hurtado López (2014), este modelo se compone de varios elementos que permiten abstraer los procesos de recepción, integración, activación y transmisión de señales que ocurren en una célula nerviosa.

- Entradas sinápticas: Representan las señales que llegan a una neurona a través de múltiples canales o conexiones, estos asociados a un peso sináptico que cuantifica la eficacia de la transmisión hacia el soma.
- Entrada neta: Corresponde al proceso de combinar las señales entrantes ponderadas por sus pesos sinápticos. Usualmente, se emplea una suma ponderada (modelo Σ sigma), aunque en algunos casos puede utilizarse un producto ponderado (modelo π pi). Este proceso simula la integración de potenciales postsinápticos que ocurre en la red dendrítica de una neurona real.
- Función de activación: Transforma la señal integrada en un nivel de salida que representa el grado de excitación neuronal. Esta función imita la respuesta del soma ante los estímulos combinados.
- Salida neuronal: Indica la probabilidad de que la neurona genera una señal de salida, análoga al disparo de un potencial de acción. En los modelos computacionales, esta salida puede ser determinista o probabilística, y se proyecta hacia otras neuronas dentro de la red.

Figura 15.
Neurona artificial basada en la biología.

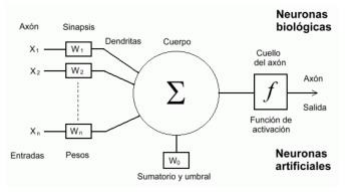
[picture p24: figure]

Nota. Tomado de: “Equivalencia entre redes artificiales y biológicas”, por; A. Requena, R. Quintanilla, J. M. Bolarín, A. Vázquez, A. Bastida, J. Zúñiga y L. M. Tomás., s.f. https://www.um.es/LEQ/Atmosferas/Ch-VI-3/F63s4p3.htm

En este contexto, Wilson (1999) propuso un modelo de tasa de disparo continua, ampliamente adoptado en redes neuronales artificiales y modelos dinámicos bioinspirados, que permite capturar comportamientos complejos de manera eficiente desde el punto de vista computacional.

τ ∙ dydt = (−y + φ(Σωi ∙ xi)) | (4)
- y→ Frecuencia de disparo media de una neurona y
- τ → Constante de tiempo de carga y descarga
- ωi→ Peso sináptico desde la neurona xi hacia la neurona y
- xi→ Señal proveniente de la neurona xi
- φ→ Función de activación

La evidencia científica afirma que el modelo dinámico continuo de Wilson (1999) representa una aproximación eficiente y biológicamente coherente para describir la actividad neuronal en términos de tasas promedio de disparo, sentando las bases para el diseño de redes neuronales biológicamente inspiradas aplicadas al control adaptativo y al procesamiento sensoriomotor.

### 5.2.6.3 Función de activación

La elección de la función de activación es un elemento fundamental ya que determina cómo se transforma la información dentro de cada neurona artificial y, por tanto, cómo se comporta dinámicamente toda la red (Parhi y Nowak, 2020). En la tabla 3 se presentan algunas funciones de activación comúnmente aplicadas de acuerdo a la aplicación (Rosenblatt, 1962).

Tabla 3.
Funciones de activación

Función de
activación | Ecuación matemática | Rango | Gráfica
Escalón | | [(0,+ 1) (-1,+1)]
Sigmoidea | | [(0,+ 1) (-1,+1)]
Tangente hiperbólica | | (-1, +1)
Sinusoidal | | [-1,+ 1]
Gaussiana | | [0,+ 1]

### 5.2.6.4 Funciones de transferencia

La elección del tipo de función de transferencia en el diseño de redes neuronales biológicamente inspiradas es fundamental ya que determina la manera en que una neurona modelada procesa, transforma y transmite las señales entrantes, condicionando tanto la fidelidad biológica del modelo como su rendimiento dinámico y computacional (Wlodzislaw y Jankowski, 2001).

De acuerdo con Ramírez Moreno y Hurtado López (2014), las funciones de transferencia permiten representar el proceso mediante el cual la neurona convierte su entrada neta — la suma ponderada de las señales sinápticas — en una respuesta de salida acotada. A continuación, se presenta un listado de algunas funciones de transferencia comúnmente utilizadas:

- Tangente Hiperbólica → f(x) =

1−e

−2x
1+e⁻²x
- Función Logística → f(x) =

1
1+e⁻x
- Función Naka-Rushton → f(x) =

x

n
σn+x

n

, n ∈ N

- Función Gaussiana → f(x) = e

−

x

2
2σ2
- Función de Base Radial → f(x) = e

−x

2

### 5.2.7 Interfaz gráfica de usuario

Una Interfaz Gráfica de Usuario (GUI, por sus siglas en inglés) se define como un entorno visual que permite la interacción entre el usuario y un sistema computacional mediante elementos gráficos como botones, menús, ventanas y paneles visuales. De acuerdo con Banerjee et al. (2013), las GUI constituyen un componente esencial del software, ya que no solo determinan la experiencia del usuario, sino que también influyen directamente en la verificación, el control y la validación de las funciones del sistema.

En nuestro contexto, la GUI adquieren un papel fundamental al servir como puente entre los componentes físicos (sensores, actuadores y controladores) y las capas lógicas de procesamiento. Su implementación permite monitorizar variables críticas del sistema — como posición, velocidad, entre otras—, visualizar el comportamiento dinámico de los procesos y modificar parámetros de control de manera interactiva sin necesidad de intervención directa sobre el software.

### 6. METODOLOGÍA

### 6.1 DISEÑO E IMPLEMENTACIÓN DEL SISTEMA BALL AND PLATE

En esta sección se exponen las consideraciones técnicas y decisiones metodológicas adoptadas durante el proceso de diseño e implementación del sistema “ball and plate”. El desarrollo de esta sección busca establecer los requerimientos funcionales, estructurales y operativos que orientaron el camino a seguir para la construcción del sistema de este modo asegurando el cumplimiento de los objetivos planteados en esta investigación. De manera general, se definen los criterios de diseño, selección de componentes y parámetros geométricos que permitieron materializar la estructura física y electrónica del sistema.

Como se expuso en el marco teórico, existen múltiples configuraciones posibles dentro de los manipuladores paralelos, la pertenencia en algún subgrupo de clasificación depende del número de grados de libertad, la disposición de los actuadores, el tipo de articulaciones, la forma en que los eslabones conectan la base fija con la plataforma móvil, entre otras (Zeeshan et al., 2012). En este contexto, el sistema propuesto adopta una morfología inspirada en la cinemática de la plataforma Stewart.

### 6.1.1 Consideraciones cinemáticas del sistema

El análisis cinemático constituye la base primordial para el diseño del sistema, al permitir establecer la relación entre los desplazamientos de los actuadores y las variaciones angulares de la plataforma móvil con el objetivo de controlar la posición de la esfera.

En esta fase de diseño, se evaluaron diferentes configuraciones mecánicas para el sistema — basando en los resultados obtenido de investigaciones de la misma índole — principalmente aquellas que permiten movimientos en dos (2GDL) y tres grados de libertad (3GDL) (Tudić et al. 2022; Xingzhe et al. 2004).

La primera alternativa, su configuración mecánica restringe el movimiento de la plataforma móvil a dos grados de libertad, correspondientes a las rotaciones alrededor de los ejes X y Y. Su principal ventaja radica en la simplicidad mecánica y electrónica, facilitando el control y la implementación. Sin embargo, su limitación se encuentra en la ausencia de desplazamiento vertical (Z), restringiendo la posibilidad de ejecutar trayectorias tridimensionales y el análisis completo de control en espacio cartesiano. Además, la linealización del modelo suele ser una aproximación válida solo para pequeñas inclinaciones, reduciendo la precisión ante movimientos amplios o dinámicos (Bdoor et al., 2016).

La segunda alternativa se basa en un manipulador paralelo tipo 3RRS (Revoluta– Revoluta–Esférica). Esta configuración permite que la plataforma móvil realice dos movimientos rotacionales — inclinaciones alrededor de los ejes X y Y— y una traslación vertical en el eje z, que, retornando al marco teórico, es un modelo simplificado de la plataforma Stewart. Otra característica relevante es la no linealidad acentuada del modelo, que surge del acoplamiento entre los movimientos rotacionales y traslacionales, así como de la relación no lineal entre los actuadores y la posición de la bola. Este comportamiento convierte a este sistema en el ideal para el desarrollo y validación de estrategias de control (Pour et al., 2016).

Contemplado estos dos hallazgos se definió como punto de partida la configuración de 3RRS de los manipuladores paralelos. En concordancia con el proceso asociado al diseño cinemático en la tabla 2 se establecen los criterios que garanticen tanto la factibilidad física como el desempeño dinámico del sistema.

Tabla 4.
Criterios cinemáticos del sistema
Criterio | Descripción técnica y justificación

Espacio de trabajo prescrito

Este criterio garantiza que los movimientos angulares de la plataforma cubran las inclinaciones máximas requeridas sin comprometer la precisión ni la estabilidad del sistema.

Capacidad de generación de fuerza y velocidad

La configuración geométrica del sistema debe permitir que los actuadores produzcan las fuerzas y velocidades necesarias en los tres ejes de movimiento.

Factibilidad geométrica de los eslabones

Las longitudes efectivas de los eslabones deben ser físicamente realizables, de modo que aseguren una correcta transmisión del movimiento entre la base fija y la plataforma móvil.

Prevención de interferencias mecánicas

La disposición de los puntos de anclaje, articulaciones y actuadores debe diseñarse de tal manera que se
eviten | colisiones | o | interferencias | entre | los
componentes durante la operación.

El cumplimiento de estos criterios puede lograrse mediante procesos heurísticos, haciendo uso del modelado CAD en el proceso, obteniendo como resultado un modelo confiable a materializar.

### 6.1.2 Requerimientos funcionales y características estructurales

Para la determinación de los requerimientos funcionales y estructurales se llevó a cabo un desarrollo paralelo que permitió identificar, a grandes rasgos, los procesos y operaciones implícitos en el funcionamiento del sistema. El uso de la ingeniería inversa y del análisis funcional desempeñó un papel fundamental, ya que, a partir del estudio de proyectos de naturaleza similar, fue posible establecer la base teórica sobre la cual se definieron los componentes y subsistemas del diseño. En la Figura 16 se presenta el diagrama de bloques del sistema del cual deriva el diagrama de caja transparente de la figura 17, herramienta que permitió visualizar la interacción entre los elementos funcionales y físicos del sistema.

Figura 16.
Diagrama de bloques del sistema

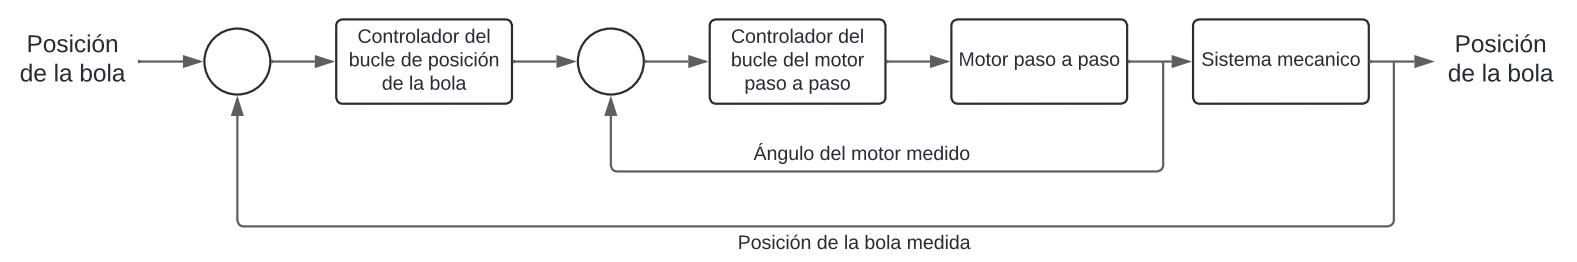
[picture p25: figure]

Figura 17.
Caja transparente del sistema

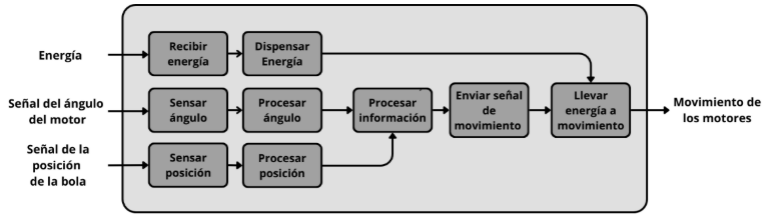
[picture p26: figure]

En el diagrama de caja transparente del sistema “ball and plate” representa la forma en que el sistema recibe y gestiona la energía, procesa la información proveniente de los sensores — encargados de medir la posición de la esfera y el ángulo de los motores — y genera las señales de control necesarias para regular su movimiento.

### 6.1.2.1 Requerimientos funcionales

Para determinar los requerimientos funcionales asociados al desempeño del sistema, se elaboró una matriz QFD (Quality Function Deployment). Esta herramienta metodológica permite traducir las necesidades del usuario en especificaciones técnicas medibles, facilitando así la alineación entre las expectativas de desempeño y las características de diseño del sistema. En primera instancia, se identificó las necesidades a satisfacer registradas en la tabla 5:

Tabla 5.
Necesidades del cliente
# | Customer Requerimients | U

1 | Se adapta dinámicamente a perturbaciones imprevistas. | 9
2 | Aprende y ajusta sus parámetros de manera autónoma en tiempo real. | 9
3 | Ajustar su respuesta ante variaciones en la carga del sistema. | 9
4 | Mantiene la estabilidad operativa en un ambiente controlado. | 9
5 | Gestiona sistemas multivariables de manera eficiente. | 3
6 | Minimiza el tiempo de respuesta ante cambios en la entrada o el entorno. | 3
7 | Se ajusta automáticamente a variaciones del proceso sin necesidad de intervención humana. | 9
8 | Optimiza el uso de energía mediante estrategias de control adaptativo. | 1
9 | Opera correctamente sin depender de modelos matemáticos precisos. | 9
10 Integra datos históricos y en tiempo real para optimizar su desempeño. | 3
11 Requiere un mantenimiento mínimo. | 9

12 Garantiza una calidad uniforme en la producción mediante ajuste automático
| de parámetros. | 3
13 Identifica patrones y optimiza su operación. | 3
14 Equilibra precisión y velocidad de respuesta sin degradar el rendimiento. | 9
15 Es compatible con plataformas de monitoreo y análisis de datos en la nube. | 1

A partir de la identificación de necesidades, se procedió a evaluar su importancia relativa empleando una escala cuadrática (1, 3 y 9). Esta ponderación permitió determinar el nivel de relevancia de cada necesidad dentro del desarrollo del sistema, evidenciando que las necesidades 2, 5 y 6 presentan una mayor prioridad al momento de orientar las decisiones de diseño y construcción del proyecto.

Posteriormente, se definió un conjunto de métricas de ingeniería orientadas a cuantificar el nivel de cumplimiento de los requerimientos del usuario. Estas métricas, representadas en la tabla 6, establecen la relación entre las necesidades identificadas y las variables técnicas del sistema:

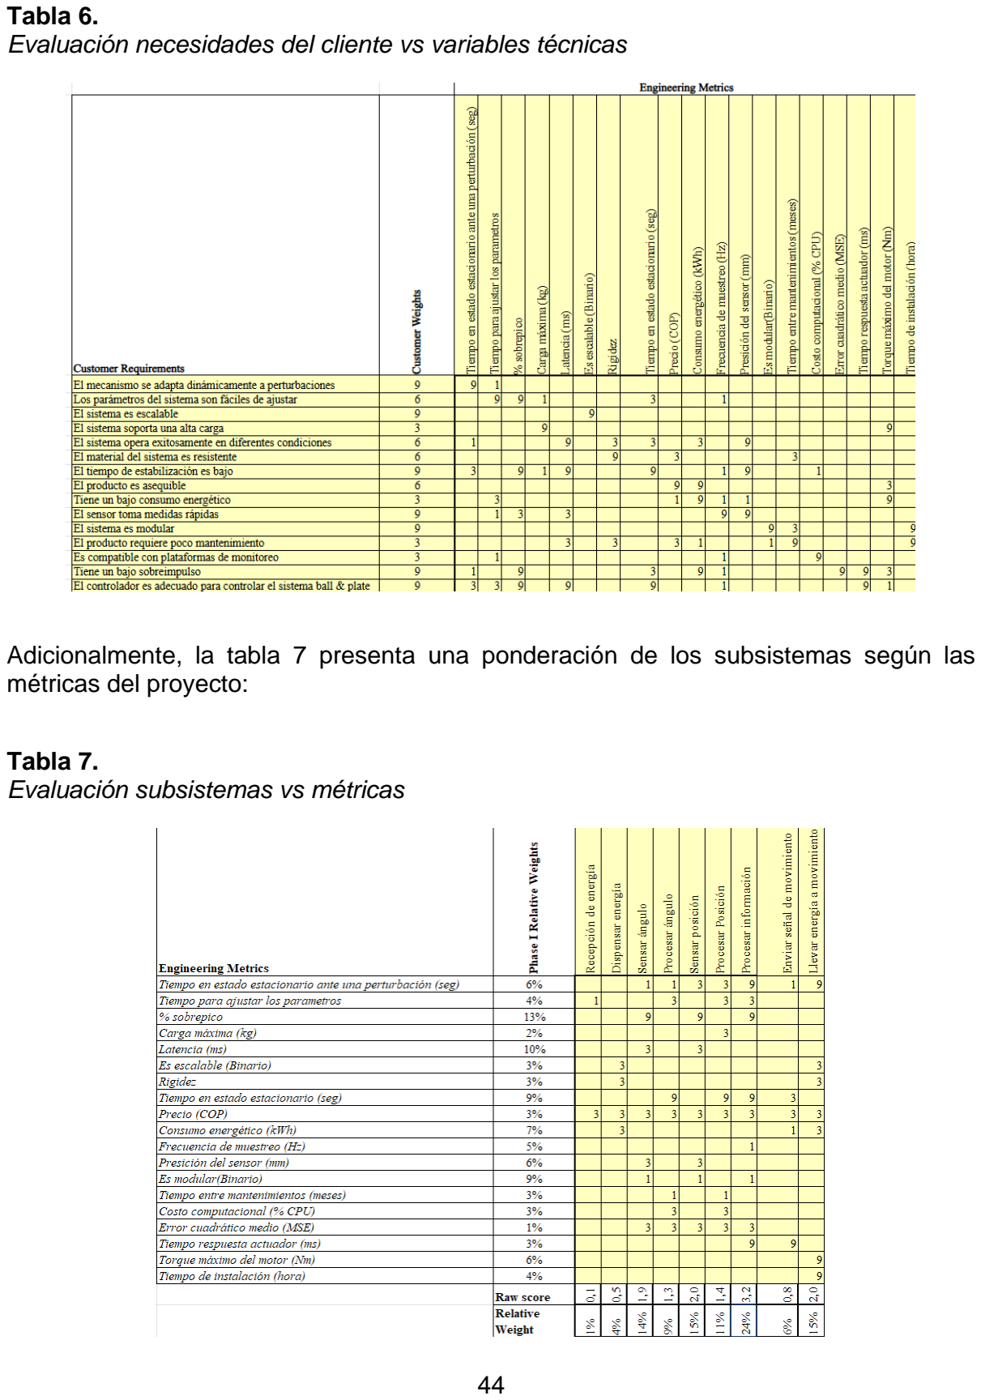
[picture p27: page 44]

Tabla 6.
Evaluación necesidades del cliente vs variables técnicas

Adicionalmente, la tabla 7 presenta una ponderación de los subsistemas según las métricas del proyecto:

Tabla 7.
Evaluación subsistemas vs métricas

Se concluye que el análisis realizado en la matriz QFD, identificó que las métricas más influyentes en el desempeño del sistema “ball and plate” corresponden al control dinámico, destacándose el sobre impulsó, el tiempo de estabilización y la latencia de comunicación. Estos parámetros determinan en gran medida la capacidad del sistema para responder con precisión ante perturbaciones externas. Como complemento, los resultados presentes en la tabla 7, evidencian una clara predominancia de la fase de procesamiento de información — responsable del cálculo y ejecución del control — con una ponderación del 24%.

En consecuencia, estos hallazgos orientan las decisiones de diseño hacia la selección de componentes que optimicen la respuesta dinámica y la fiabilidad del control. Cabe resaltar que, debido a su extensión, el proceso detallado de desarrollo de la QFD no se presenta en este informe, aunque los resultados expuestos sintetizan los aspectos más relevantes del análisis realizado.

### 6.1.2.2 Características estructurales

Establecemos como principio los resultados obtenidos en las secciones anteriores, de este modo logramos orientar las características mecánicas que tendrá el sistema para satisfacer las necesidades evaluadas:

- Estructura 3RRS:

Se establece que el sistema adopta una topología 3RRS, donde tres cadenas cinemáticas independientes conectan la base fija con la plataforma móvil. Cada cadena está compuesta por dos articulaciones revolutas (R) y una esférica (S) en su extremo. La primera articulación revoluta (Brazo) se encuentra directamente acoplada al eje del actuador, mientras que la segunda se dispone en el punto de unión entre el brazo y un segundo eslabón, Esta disposición permite un rango de movimiento angular amplio facilitando la inclinación de la plataforma en los ejes X y Y, además de una ligera traslación en el eje Z. Finalmente, la articulación esférica (S) ubicada en el extremo del segundo eslabón posibilita los ajustes tridimensionales necesarios para mantener la esfera en equilibrio.

- Distribución de esfuerzos y simetría estructural:

La carga total soportada por el sistema —constituida por la esfera, la plataforma móvil y el sensor — es baja, por lo que los actuadores no enfrentan exigencias mecánicas considerables. Además, en esta configuración las tres cadenas cinemáticas trabajan de forma cooperativa, lo que distribuye equitativamente los esfuerzos, evitando concentraciones de carga y reduciendo el desgaste de los acoplamientos.

- Longitud de eslabones y rango de movimiento:

Las longitudes de los eslabones que componen cada cadena cinemática se determinarán mediante simulaciones iterativas del modelo cinemático. Dicho análisis permitirá validar que el sistema pueda alcanzar las inclinaciones máximas requeridas sin colisiones ni pérdidas de rigidez estructural.

### 6.2 SELECCIÓN DE COMPONENTES

La selección de componentes es una etapa crítica en el diseño, determinado no solo el desempeño dinámico y estructural del sistema, sino que también su viabilidad técnica y económica. El proceso de selección no se aborda de manera arbitraria, seguirá una metodología estructurada que permite evaluar de forma objetiva las diferentes alternativas disponibles para cada subsistema, para esto se toma en consideración un valor de referencia equivalente a la neutralidad en cada criterio evaluado.

### 6.2.1 Sensores

Dentro del común en el desarrollo de sistemas ball and plate, se empleados dos medios sensoriales para la detección de la posición de la esfera sobre la plataforma móvil, cámaras y sensores táctiles (touch). Ambos permiten determinar la ubicación de la esfera, aunque lo hacen mediante principios de funcionamiento distintos.

### 6.2.1.1 Sensor basado en cámara

El uso de una cámara como sensor de posición, se fundamenta en la detección y procesamiento visual de la esfera sobre la superficie. El principio de funcionamiento consiste en convertir las imágenes capturadas en información métrica sobre la posición de la esfera. Para ello, se realiza una secuencia de operaciones computacionales que generalmente incluyen:

- Adquisición de imagen: La cámara obtiene cuadros continuos de video (frames) a una frecuencia determinada, que define la tasa de actualización del sistema.
- Preprocesamiento: Se aplican filtros para reducir ruido y mejorar el contraste, facilitando la identificación de la esfera sobre el fondo.
- Segmentación: Se emplean métodos de detección de color, umbralización o detección de contornos para aislar la región correspondiente a la esfera.

- Extracción de características: Una vez identificada la esfera, se determina su centroide (coordenadas X, Y).
- Conversión a coordenadas físicas: Las coordenadas (X,Y) se transforman en unidades métricas que representan la posición real de la esfera sobre la plataforma.

### 6.2.1.2 Sensor táctil

La pantalla táctil resistiva es un dispositivo de detección de posición que funciona bajo el principio de variación de resistencia eléctrica por contacto físico entre dos capas conductoras. Está compuesta típicamente por dos láminas transparentes — una superior flexible y otra inferior rígida —, separadas por un fino espacio con puntos aislantes microscópicos. Cuando la esfera entra en contacto con la superficie, ejerce una presión que provoca que ambas capas se toquen en un punto específico. En ese instante se forma un circuito eléctrico cerrado, permitiendo medir la resistencia resultante en los ejes X y Y.

Conociendo el principio de funcionamiento de cada sensor, se elaboró una matriz de tamizaje, tabla 8, para evaluar y seleccionar el método de sensado más adecuado para el sistema. Esta ponderación se realizó considerando los siguientes criterios: rapidez, simplicidad, eficiencia y adecuación al entorno de control en tiempo real.

Tabla 8.
Matriz de tamizaje – Sensor
| Closed Loop
Sensor | Ball & Plate
System
Criterio de selección | Pantalla
| Resistiva | Cámara | Ref

El mecanismo se adapta
dinámicamente a perturbaciones | 0 | - | 0

El sistema opera exitosamente en
diferentes condiciones | 0 | + | 0
El tiempo de estabilización es bajo | 0 | - | 0
El sensor toma medidas rápidas | 0 | - | 0
Tiene un bajo sobre impulsó | 0 | - | 0
Positivos | 0 | 1
Iguales | 5 | 0
Negativos | 0 | 4
Total | 0 | -3
Orden | 1 | 2

### 6.2.1.3 Actuadores

Los actuadores son aquellos elementos encargados de generar el movimiento angular necesario para modificar la inclinación de la plataforma y con ello controlar la posición de la esfera. Las opciones que se evaluaron fueron puestas como oportunas conociendo la topología escogida previamente para el diseño, este factor elimina automáticamente los actuadores prismáticos. A continuación, se describen los principios de funcionamiento de cada opción.

- Motor Dynamixel

Los motores Dynamixel son actuadores inteligentes de tipo servomotor DC que integran en un mismo módulo el motor, la caja reductora, los sensores de posición y temperatura, y la electrónica de control. Su principio de funcionamiento se basa en el control por realimentación cerrada, en el que la posición, velocidad y corriente del eje se monitorizan constantemente mediante sensores internos. Cada unidad Dynamixel dispone de un microcontrolador embebido que permite operar bajo distintos modos de control: posición, velocidad o torque, comunicándose con el sistema principal a través de un bus serial digital.

- Motor paso a paso

El motor paso a paso es un actuador electromecánico que convierte impulsos eléctricos discretos en desplazamientos angulares definidos. A diferencia de los motores DC convencionales, su eje gira en incrementos fijos (pasos) determinados por el número de polos del estator y el rotor. En el modo de control abierto, la posición se asume por conteo de pasos; sin embargo, en un motor paso a paso de bucle cerrado, esta limitación se supera mediante la incorporación de un encoder que mide la posición real del eje (Iqteit, et al., 2022).

El control del motor se realiza mediante un driver o controlador de pasos, que gestiona la conmutación de las bobinas en diferentes modos de operación (Paso completo, medio paso o micro pasos) permitiendo alcanzar movimientos más suaves y precisos.

- Motor Brushless (BLDC)

El motor brushless de corriente continua (BLDC) es un actuador eléctrico que combina la eficiencia de los motores DC con la durabilidad y control de los motores síncronos de imanes permanentes. Su principio de funcionamiento se fundamenta en la conmutación electrónica de las corrientes aplicadas a las bobinas del estator, eliminando el uso de escobillas y conmutadores mecánicos presentes en los motores DC convencionales. No obstante, su implementación requiere un controlador más complejo y un sistema de sensado preciso para garantizar la correcta conmutación de las fases y evitar pérdidas de sincronización.

La elección del actuador para el sistema se justificará principalmente por su desempeño equilibrado frente a los distintos criterios de evaluación técnicos, operativos y económicos establecidos. De acuerdo con la matriz de tamizaje presentada en la tabla 9.

Tabla 9.
Matriz de tamizaje – Motor
Motor | | | | Closed Loop Ball &
| | | | Plate System
Criterio de selección | Dynamixel | Paso a
| | paso | Brushless | Ref

El mecanismo se adapta
dinámicamente a perturbaciones | + | + | - | 0

Los parámetros del sistema son
fáciles de ajustar | 0 | 0 | - | 0
El sistema soporta una alta carga | - | 0 | + | 0
El sistema opera exitosamente en
diferentes condiciones | 0 | 0 | - | 0
El tiempo de estabilización es bajo | + | + | - | 0
El producto es asequible | - | + | - | 0
Tiene un bajo consumo energético | 0 | 0 | + | 0
El producto requiere poco
mantenimiento | 0 | 0 | + | 0
Tiene un bajo sobre impulsó | 0 | + | - | 0
Positivos | 2 | 4 | 3 | 0
Iguales | 5 | 5 | 0
Negativos | 2 | 0 | 6
Total | 0 | 4 | -3
Orden | 2 | 1 | 3

### 6.2.2 Elementos para el procesamiento

El elemento de procesamiento es el núcleo lógico del sistema, siendo responsable de la ejecución de los algoritmos de control, la adquisición de datos sensoriales y la comunicación con los actuadores. En términos generales, todas las plataformas de procesamiento — independientemente de su arquitectura — cumplen la misma función fundamental, recibir información de entrada, procesarla mediante un conjunto de instrucciones programadas y generar señales de salida que gobiernan el comportamiento del sistema físico.

Sin embargo, cada tecnología ejecuta esta función bajo arquitecturas de hardware y software diferentes, lo que afecta parámetros como la capacidad de cómputo, la velocidad de procesamiento, el soporte de periféricos y la facilidad de programación. Entre las opciones más relevantes para el sistema se consideran tres alternativas, Raspberry Pi 5, Arduino Mega 2560 y ESP32. En la tabla 10 se realiza la matriz de tamizaje para la selección del elemento de procesamiento.

Tabla 10.
Matriz de tamizaje – Elementos de procesamiento
Elementos de procesamiento | Closed Loop Ball &
Plate System
Criterio de selección | Raspberry
| Pi 5 | Arduino
| | Mega 2560 | ESP32 | Ref
Capacidad de procesamiento | + | 0 | + | 0
Facilidad de programación e
integración | 0 | + | + | 0

Latencia en tareas de control en
tiempo real | + | 0 | + | 0

Capacidad de comunicación
(interfaces y conectividad) | + | - | + | 0
Consumo energético | - | + | + | 0
Escalabilidad del sistema | + | 0 | + | 0
Costo | - | + | + | 0
Positivos | 4 | 3 | 7
Iguales | 1 | 3 | 0
Negativos | 2 | 1 | 0
Total | 2 | 3 | 7
Orden | 3 | 2 | 1

A partir del análisis comparativo, la ESP32 es la mejor opción para desempeñar el rol de elemento principal de procesamiento en el sistema. No obstante, tras las pruebas de compatibilidad realizadas durante el desarrollo, se determinó que la combinación del microcontrolador ATmega2560 con la ESP32 ofrece una arquitectura de procesamiento integral que optimiza la eficiencia global del sistema. Esta configuración híbrida incorpora la placa RAMPS 1.4, la cual simplifica el control directo de motores paso a paso al permitir la integración sencilla de drivers de potencia, garantizando una gestión confiable de las señales PWM y reduciendo la complejidad del cableado. Por su parte, el ESP32 asume las tareas de procesamiento de alto nivel, comunicación inalámbrica y coordinación general del sistema.

### 6.3 DISEÑO FÍSICO Y ENSAMBLAJE

### 6.3.1 Diseño del sistema mecánico y estructural

Para el desarrollo de los diferentes componentes mecánicos y estructurales se empleó el software SolidWorks 2024, herramienta CAD (Diseño Asistido por Computadora) que permite diseñar, modelar y validar cualquier componente o pieza mecánica de forma eficiente en un entorno 3D. Asimismo, el modelado facilitó el análisis preliminar de interferencias, el estudio de movimientos y la verificación funcional del diseño antes de su fabricación física por medio de un proceso heurístico, asegurando la coherencia entre la geometría del modelo y los requerimientos operativos del sistema.

### 6.3.1.1 Diseño de la base fija

La base fija se diseñó con forma de disco dentado de tres secciones, permitiendo una disposición triangular de los actuadores que garantiza una distribución equilibrada de cargas. En su superficie se incorporan orificios pasantes que facilitan el montaje mediante tornillería y la fijación de las escuadras de soporte y las carcasas de los motores paso a paso. Además, se integraron aberturas para el paso ordenado del cableado hacia la zona inferior de la estructura, optimizando la organización y el mantenimiento del sistema. La base fija posee un diámetro de 85 mm, un área de 18 553.51 mm² y un espesor de 4 mm.

Figura 18.
CAD de la base fija

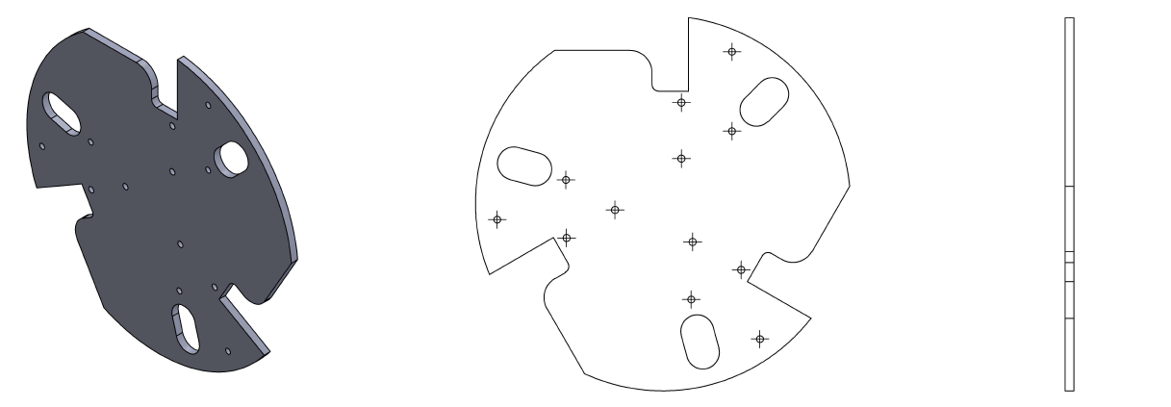
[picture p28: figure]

### 6.3.1.2 Diseño de las escuadras de fijación para los actuadores

Las escuadras de fijación fueron diseñadas para satisfacer una doble función; por un lado, permiten la unión mecánica entre los actuadores y la base fija mediante tornillería absorbiendo vibraciones; segundo, aportan soporte estructural adicional, en un diseño preliminar estas facilitaban el montaje de otros elementos electrónicos de control. Sin embargo, con la evolución del diseño del sistema su función se concentró en la fijación mecánica precisa. Cada escuadra presenta un área de 2731.27 mm², una altura de 90.8 mm.

Figura 19.
CAD de las escuadras de fijación para los actuadores

### 6.3.1.3 Diseño del brazo

El brazo forma parte esencial de la cadena cinemática, junto con el eslabón pasivo y el conector esférico Traxxas. Su función principal es transmitir el movimiento rotacional del eje del motor hacia el resto de la estructura. La fijación al eje del actuador se ajusta mediante un tornillo de apriete que asegura su conexión. Durante el proceso de desarrollo se realizaron varios rediseños. Inicialmente, el brazo estaba constituido por tres piezas, pero las pruebas experimentales evidenciaron fracturas por concentración de esfuerzos en zonas críticas debido al torque y a los movimientos repetitivos. Como resultado, se rediseñó la geometría y se incrementó el espesor en zonas estratégicas, logrando una mejora significativa en la resistencia mecánica. El volumen final de la pieza es de 5446.31 mm³.

Figura 20.
CAD del brazo

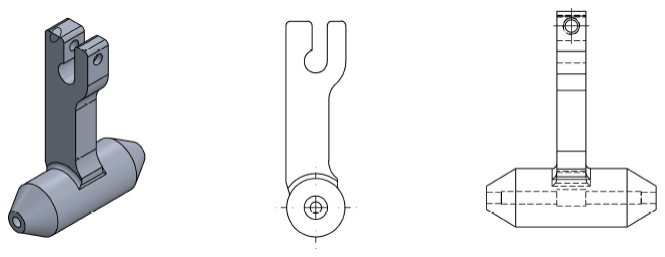
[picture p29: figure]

### 6.3.1.4 Diseño del eslabón pasivo

El eslabón constituye el segundo elemento de la cadena cinemática. Su geometría permite la distribución uniformemente los esfuerzos transmitidos por el brazo y la rótula. Al igual que el brazo, originalmente estaba compuesto por tres partes, pero fue sintetizado en una sola pieza para mejorar su resistencia y simplificar el ensamblaje. Durante su evolución, las ramas pasaron de una sección circular a una cuadrada, mejorando el comportamiento estructural frente a torsión y flexión. El eslabón posee un volumen de 5 192.89 mm³ y un ángulo de 32.21° entre las ramas.

Figura 21.
CAD del eslabón pasivo

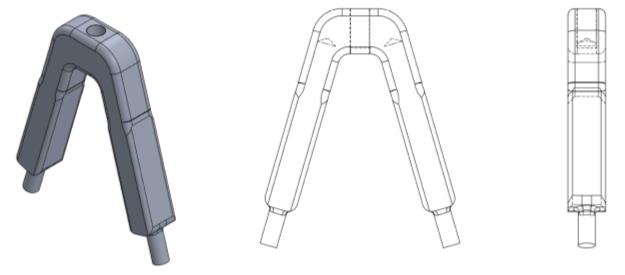
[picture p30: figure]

### 6.3.1.5 Rotulas esféricas

Las rótulas esféricas, aunque no fueron diseñadas para este proyecto, cumplen un papel fundamental en la articulación del sistema. Permiten la conexión entre el brazo, el eslabón pasivo y la plataforma móvil, facilitando los movimientos de inclinación característicos del sistema. En la unión entre brazo y eslabón pasivo, la rótula se encuentra parcialmente restringida por la geometría del diseño, limitando su rotación; sin embargo, la conexión con la plataforma móvil mantiene un movimiento esférico. Las rótulas utilizadas son de la marca Traxxas.

Figura 22.
Rotulas esféricas

### 6.3.1.6 Diseño de la plataforma móvil

La plataforma móvil cumple la función de soportar el sensor y a la vez de actuar como la superficie en donde se desplazará la esfera. Se conecta al eslabón pasivo mediante una rótula esférica, cerrando la cadena cinemática 3RRS. En nuestra propuesta de diseño y con el fin de dar robustez al mismo, su subensamble se encuentra constituido por de 3 componentes, manteniendo un bajo peso evitando comprometer la integridad estructura.

Figura 23.
CAD de plataforma móvil

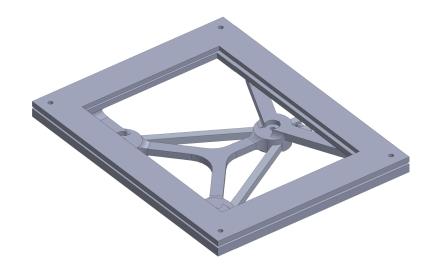
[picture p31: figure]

### 6.3.1.7 Diseño de la carcasa de motor paso a paso

Las carcasas de los motores paso a paso logran satisfacer dos necesidades de diseño, la primera asociada a la estética del sistema permitiendo identificar visualmente cada actuador, lo que facilita el diagnóstico y la calibración durante las pruebas experimentales. En segundo lugar, contribuyen a la reducción de vibraciones generadas por el funcionamiento de los motores.

Figura 24.
CAD de la carcasa de motor paso a paso

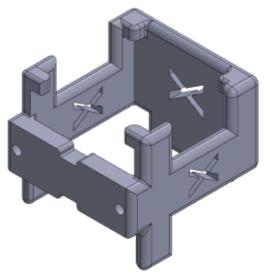
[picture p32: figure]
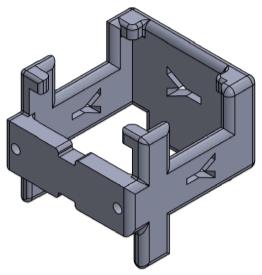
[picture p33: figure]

### 6.3.1.8 Diseño del cuerpo estructural

Esta pieza representa el mayor volumen de todo el sistema. Su diseño inicial buscaba asemejarse a un Módulo de Tripulación (Crew Module o CM); sin embargo, por limitaciones de manufactura, se optó por una forma de tronco de pirámide hexagonal. Su función principal es servir como la estructura de soporte del conjunto completo del sistema, unificando todos los elementos descritos anteriormente. En su interior se alojan el cableado, los componentes electrónicos y las placas de procesamiento, garantizando una disposición ordenada y protegida. En su parte externa se integran la pantalla TFT y el módulo joystick, destinados a la interacción con el usuario. El cuerpo estructural está constituido por 37 piezas en total.

Figura 25.
CAD del cuerpo estructural

### 6.3.1.9 Ensamble completo

Figura 26.
Ensamble completo

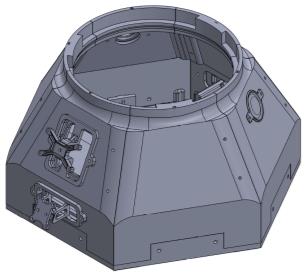
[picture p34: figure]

### 6.3.2 Selección del material estructural y método de manufactura

### 6.3.2.1 Selección del material estructural

Para la selección del material estructural se aplicó la misma metodología empleada en la evaluación de actuadores, sensores y elementos de procesamiento, es decir, un proceso comparativo basado en criterios establecidos en relación a factores mecánicos, económicos y de manufactura. Para este sistema se consideraron tres materiales de uso común en prototipos: Aluminio 6061, PLA (ácido poliláctico) y ABS (acrilonitrilo butadieno estireno). La tabla 11 presenta con algunas propiedades físicas que influencian de forma directa la selección.

Tabla 11.
Propiedades físicas de materiales

Material
Propiedad | Aluminio 6061 (T6) | PLA (Ácido
Poliláctico)

ABS (Acrilonitrilo
Butadieno Estireno)
Densidad (g/cm3) | 2.70 | 1.21−1.43 | 1.04−1.07
Punto de Fusión (°C) 580−650 (Rango de
fusión)

150−180 (Transición
vítrea)

105−120 (Transición
vítrea)
Resistencia a la
Tracción (MPa) | 290−310 | 50−65 | 40−55
Límite Elástico (MPa) | 240−275 | 40−60 | 30−45
Módulo de
Elasticidad (GPa) | 68.9 | 2.7−4.0 | 1.8−2.5

Coeficiente de
Expansión Térmica
(C)
23.4 | 68−120 | 70−100

Dureza (HB - Brinell /
Escalas Relativas) 95 HB (Brinell)

No aplica
(Termoplástico
blando)

No aplica
(Termoplástico
tenaz)

En la tabla 12 se evalúa la matriz de tamizaje para la selección del material.

Tabla 12.
Matriz de tamizaje – Material
Material | | | | Closed Loop Ball &
| | | | Plate System
Criterio de selección | Aluminio | ABS | PLA | Ref
El sistema es escalable | 0 | + | + | 0
El sistema soporta una alta carga | + | 0 | 0 | 0
El sistema opera exitosamente en
diferentes condiciones | + | 0 | 0 | 0
El producto es asequible | 0 | + | + | 0
Método de manufactura | - | + | + | 0
Compatibilidad con rediseños o prototipado
rápido | - | 0 | + | 0
Reemplazo de piezas | 0 | + | + | 0
Positivos | 0 | 1 | 2
Iguales | 6 | 0 | 0
Negativos | 0 | 5 | 4
Total | 0 | -4 | -2
Orden | 4 | 1 | 2

### 6.3.2.2 Método de manufactura

Como se evidencio en la sección anterior, un factor determinante en la selección del PLA es su procesabilidad mediante manufactura aditiva (impresión 3D por deposición fundida, FDM). Este método permite fabricar geometrías complejas con alta precisión, reducir costos de producción y facilitar iteraciones rápidas en el diseño. La fabricación de las piezas se realizó en dos impresoras 3D de tecnología FDM — Bambu Lab A1 y Creality K1C —, configuradas con los parámetros que se muestran en la tabla 13:

Tabla 13.
Parámetros de impresión por deposición fundida
PARÁMETRO | VALOR / CONFIGURACIÓN | UNIDAD / ONSERVACIÓN
Altura de capa | 0.20 | mm
Porcentaje de relleno (infill) | 15 | %
Velocidad de impresión | 300 | mm/s
Temperatura de cama | 65 | °C

Temperatura del extrusor (1.ª
capa) | 215 | °C

Temperatura del extrusor
(resto de capas) | 210 | °C
Material | PLA (ácido poliláctico) | Filamento de 1.75 mm
Impresoras utilizadas | Bambu Lab A1 / Creality K1C | —

Tiempo total estimado de
impresión | 45 | horas

### 6.4 CONSTRUCCIÓN DEL SISTEMA

Figura 27.
Sistema “Ball and plate” físico

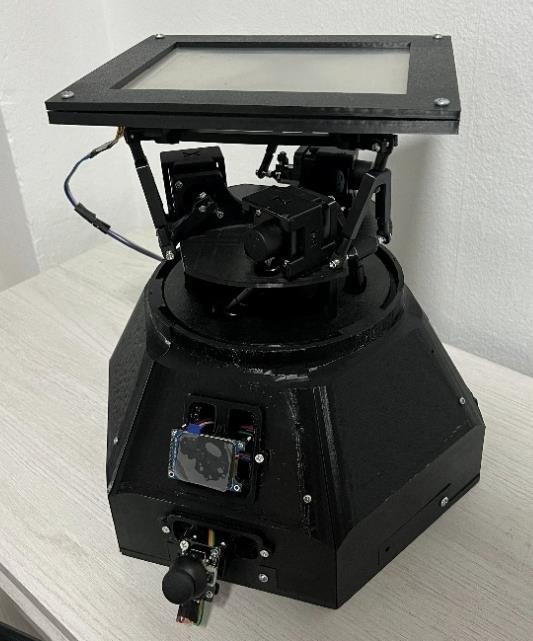
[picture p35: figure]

### 6.5 DISEÑO ELECTRÓNICO

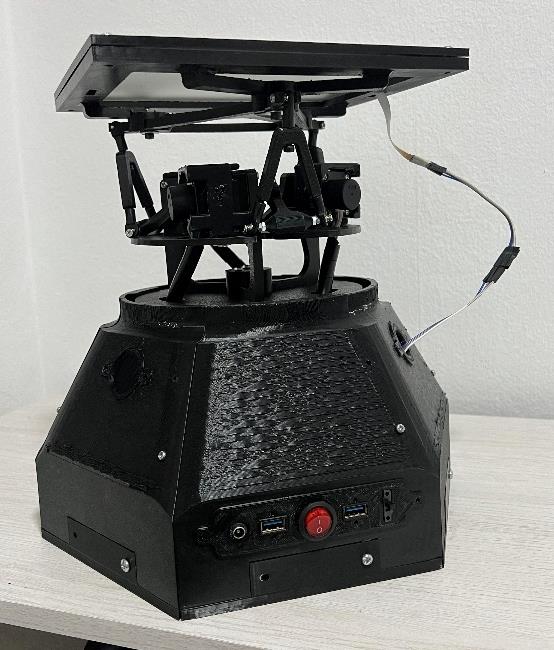
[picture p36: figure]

Recordando los objetivos de funcionamiento y los componentes electrónicos definidos para el sistema, se llevó a cabo un mapeo preliminar de pines que permitió establecer la correspondencia entre las señales de control, sensado y comunicación. Este proceso incluyó la asignación detallada de los pines de la ESP32, la placa RAMPS 1.4 y el microcontrolador ATmega2560, garantizando una correcta interconexión entre los módulos y un funcionamiento coherente del sistema en su conjunto. La tabla 14 presenta el mapeo de pines realizado a la ESP32 WROOM:

Tabla 14.
Mapeo pines ESO32 WROOM
| | | DESCRIPCIÓN | | | | DESCRIPCIÓN
PIN | FUNCIÓN | ASIGNACION | DE | PIN | FUNCIÓN | ASIGNACIÓN | DE
ASIGNACIÓN | | | | ASIGNACIÓN

EN

Chip Enable –
reinicia o habilita
el
microcontrolador

GPIO23
(VSPI
MOSI)

Salida de
datos SPI
(Master Out
Slave In)

MOSI
(RAMPS 1.4)

Comunicación
SPI hacia la
placa RAMPS
1.4 para
transmisión de
datos al
controlador de
motores.
GPIO36
(VP /
ADC0)

Entrada
analógica (solo
lectura)

GPIO22
(I2C
SCL)

Línea de
reloj del bus
I2C

GPIO39
(VN /
ADC3)

Entrada
analógica (solo
lectura)

GPIO1
(TX0)

Transmisión
UART
principal

GPIO34
(ADC6)

Entrada
analógica (solo
lectura)

VRY (Módulo
Joystick)

Lectura del eje
vertical del
joystick
analógico.

GPIO3
(RX0)

Recepción
UART
principal

GPIO35
(ADC7)

Entrada
analógica (solo
lectura)

VRX (Módulo
Joystick)

Lectura del eje
horizontal del
joystick
analógico.

GPIO21
(I2C
SDA)

Línea de
datos del
bus I2C

GPIO32
(ADC4 /
TOUCH9)

Entrada
analógica o táctil | - | -

GPIO19
(VSPI
MISO)

Entrada de
datos SPI
(Master In
Slave Out)

MISO
(RAMPS 1.4)

Comunicación
SPI para
recepción de
datos desde
RAMPS 1.4.

GPIO33
(ADC5 /
TOUCH8)
Entrada analógica o táctil | SW (Módulo
| Joystick) | Lectura del
| | pulsador
| | central del
| | joystick.

GPIO18
(VSPI
CLK)

Señal de
reloj SPI

SCK (RAMPS
1.4)

Sincronización
del bus SPI
hacia la
RAMPS 1.4.

GPIO25
(DAC1 /
TOUCH6)
Salida analógica (DAC1) o táctil | SC (Pantalla
TFT)
| | Señal de
| | selección de
| | chip para
| | habilitar la
| | pantalla TFT.

GPIO5
(VSPI SS
/ CS0)

Chip Select
SPI

D53 (RAMPS
1.4)

Señal de
selección de
dispositivo en
comunicación
SPI con
RAMPS.

GPIO26
(DAC2 /
TOUCH7)
Salida analógica (DAC2) o táctil | SDA (Pantalla
TFT)
| | Línea de datos
| | serie para
| | transmisión
| | hacia la
| | pantalla TFT.

GPIO17
(TX2)

Transmisión
UART
secundaria

GPIO27
(ADC2 /
TOUCH7)

Entrada
analógica o táctil

SCL (Pantalla
TFT)

Señal de reloj
serie para
sincronización
de la pantalla
TFT.

GPIO16
(RX2)

Recepción
UART
secundaria

GPIO14
(HSPI
CLK /
TOUCH6)

Señal de reloj
SPI o entrada
táctil

GPIO4
(ADC2 /
TOUCH0)

Entrada
táctil o
analógica

RES (Pantalla
TFT)

Control de
reinicio del
módulo TFT.

Tabla 14. (Continuación)

| | | DESCRIPCIÓN | | | | DESCRIPCIÓN
PIN | FUNCIÓN | ASIGNACION | DE | PIN | FUNCIÓN | ASIGNACIÓN | DE
ASIGNACIÓN | | | | ASIGNACIÓN
GPIO12
(HSPI
MISO /
TOUCH5)

Entrada SPI o
entrada táctil | - | -

GPIO2
(ADC2 /
TOUCH2)

Entrada
táctil o
analógica

DC (Pantalla
TFT)

Línea de control
de
datos/comandos
del módulo TFT.

GPIO13
(ADC2 /
TOUCH4)

Entrada táctil
o SPI | - | -

GPIO15
(ADC2 /
TOUCH3)

Entrada
táctil o señal
SPI
secundaria

NO
ASIGNADO | -
GND | Tierra | Tierra común

Referencia
eléctrica común
de todo el
sistema.
GND | Tierra | GND COMÚN

Conexión a la
tierra del
circuito, esencial
para estabilidad
eléctrica.

VIN

Entrada de 5
V
(alimentación
externa)

SWITCH DE
ENCENDIDO

Conecta la
alimentación
principal de 5 V
al sistema.

3V3

Salida
regulada de
3.3 V para
periféricos
externos

BLK
PANTALLA
TFT

Alimentación del
backlight
(iluminación) de
la pantalla TFT.

La tabla 15 presenta el mapeo de pines realizado al ATMEGA 2560 en conexión directa con a la RAMPS 1.4, esta configuración se denomina del tipo “Shield”.

Tabla 15.
Mapeo pines ATmega 2560

ATMEGA
2560 | FUNCIÓN | ASIGNACIÓN | DESCRIPCIÓN DE LA ASIGNACIÓN
A5 | Entrada analógica táctil | XP (PANTALLA
| | TOUCH) | Línea positiva en el eje X de la pantalla táctil
| | | resistiva.
A12 | Entrada analógica táctil | XM (PANTALLA
| | TOUCH) | Línea negativa en el eje X de la pantalla táctil
| | | resistiva.
A10 | Entrada analógica táctil | YP (PANTALLA
| | TOUCH) | Línea positiva en el eje Y de la pantalla táctil
| | | resistiva.
A11 | Entrada analógica táctil | YM (PANTALLA
| | TOUCH) | Línea negativa en el eje Y de la pantalla táctil
| | | resistiva.
D3 | Entrada digital
| (interrupción externa) | ENCODER X
| | (ACTUADOR) | Señal A del encoder del actuador del eje X.
D2 | Entrada digital
| (interrupción externa) | ENCODER X
| | (ACTUADOR) | Señal B del encoder del actuador del eje X.
D18 | Entrada digital
| (interrupción externa) | ENCODER Y
| | (ACTUADOR) | Señal A del encoder del actuador del eje Y.
D19 | Entrada digital
| (interrupción externa) | ENCODER Y
| | (ACTUADOR) | Señal B del encoder del actuador del eje Y.
D20 | Entrada digital
| (interrupción externa) | ENCODER Z
| | (ACTUADOR) | Señal A del encoder del actuador del eje Z.
D21 | Entrada digital
| (interrupción externa) | ENCODER Z
| | (ACTUADOR) | Señal B del encoder del actuador del eje Z.
D50 | Comunicación SPI | GPIO19 (VSPI MISO –
| | ESP32) | Línea de recepción de datos (Master In Slave
| | | Out) entre ATmega2560 y ESP32.

Tabla 15. (Continuación)

ATMEGA 2560 | FUNCIÓN | ASIGNACIÓN | DESCRIPCIÓN DE LA ASIGNACIÓN
D51 | Comunicación SPI | GPIO23 (VSPI MOSI –
ESP32)

Línea de transmisión de datos (Master Out Slave In) entre ATmega2560 y ESP32.
D52 | Comunicación SPI | GPIO18 (VSPI CLK –
ESP32)

Línea de reloj de sincronización para comunicación SPI con el ESP32.
D53 | Comunicación SPI | GPIO5 (VSPI SS / CS0
– ESP32)

Línea de selección de esclavo (Chip Select) para establecer comunicación con el ESP32.
D55 | Salida digital | dirPinX | Dirección del motor paso a paso del eje X
(sentido de giro).
D54 | Salida digital | stepPinX | Generación de pulsos de paso para el motor
paso a paso del eje X.
D38 | Salida digital | enablePinX | Habilitación o deshabilitación del driver del eje
X.
D61 | Salida digital | dirPinY | Dirección del motor paso a paso del eje Y
(sentido de giro).

Finalmente, la tabla 16 recopila todos los componentes electrónicos usado en el desarrollo del sistema.

Tabla 16.
Componentes electrónicos utilizados en el sistema
COMPONENTE | MODELO | FUNCIÓN | CARACTERÍSTICA | FIGURA
Microcontrolador | ESP32

Procesamiento
complementario,
comunicación
inalámbrica y tareas
de interfaz.

Dual core 240 MHz,
Wi-Fi/Bluetooth, 4 MB
Flash, ADC, PWM, SPI,
UART.

Microcontrolador
auxiliar | ATMega 2560

Unidad principal de
control y
procesamiento de
señales.

54 pines digitales, 16
entradas analógicas,
compatible con shields
RAMPS 1.4,
comunicación UART,
I²C, SPI, USB.

Placa de
expansión | RAMPS 1.4

Interfaz entre el
Arduino y los
controladores/motores
paso a paso.

Permite controlar hasta
5 ejes, incluye
conectores para finales
de carrera,
controladores
DRV8825 y pantalla
LCD.

Drivers de motor
paso a paso

DRV8825 (x3)

Control de corriente y
microstepping de
motores paso a paso.

Voltaje de alimentación
8.2–45 V, corriente
máx. 2.2 A por fase,
hasta 1/32 de
microstepping,
protección térmica.

Tabla 16. (Continuación)

COMPONENTE | MODELO | FUNCIÓN | CARACTERÍSTICA | FIGURA

Pantalla táctil
resistiva

8.4” 4 hilos +
controlador
touch

Interfaz hombre-máquina (HMI) para
visualizar y controlar
parámetros del
sistema.

Panel resistivo de 8.4”,
4 hilos, resolución
800×600 px aprox.,
interfaz SPI/serial con
hardware de control
integrado.

Fuente de
alimentación

12 V DC – 4 A
mínimo

Suministro eléctrico
principal del sistema.

Fuente con protección
contra sobrecarga y
corto circuito, salida
estable de 12 V DC y
corriente continua
mínima de 4 A.

Convertidor DC-DC Buck

LM2596 con
voltímetro
PELV

Regulación de voltaje
para alimentar
circuitos de control.

Entrada 4–35 V, salida
ajustable 1.25–35 V,
corriente máx. 3 A,
eficiencia >90 %,
incluye voltímetro
integrado.

Pantalla gráfica
TFT

ST7789V2
(1.69”)

Visualización de
datos o gráficos del
sistema.

Resolución 240×280
px, comunicación SPI,
esquinas
redondeadas,
compatibilidad con
ESP32/Arduino.

Motor paso a
paso de bucle
cerrado

NEMA 14
(18 N·cm,
300 PPR)

Accionamiento de
ejes con control de
posición y
realimentación por
encoder.

Torque 18 N·cm,
alimentación 12 V,
incluye encoder de
300 PPR para
control de lazo
cerrado, precisión de
1.8° por paso.

Módulo de
control manual

KY-023
Joystick

Entrada analógica
para control manual
de ejes o selección
de menú.

Dos potenciómetros
analógicos (ejes
X/Y) y un pulsador
digital integrado,
salida compatible
con 5 V/3.3 V.

Interruptor de
palanca

3-Pin con luz
LED roja

Conmutación
general de
encendido/apagado
del sistema.

Voltaje nominal 250
V AC, corriente 6 A,
indicador luminoso
integrado, montaje
en panel.

Adaptador de
energía

DC-Jack a
terminal
block (2-pin)

Conexión de fuente
externa al sistema.

Permite conectar
fuentes DC mediante
tornillos y plug tipo
jack estándar
(5.5×2.1 mm).

### 6.6 GUI

Con la idea de dotar de simplicidad, en relación al modo de uso del sistema, se incorpora una interfaz gráfica de usuario (GUI) que permite la interacción directa entre el usuario y el sistema de control, integrando dos elementos principales: una pantalla TFT SPI y un módulo joystick. La tabla 17 resume la relación HMI:

Tabla 17.
Interfaz Hombre-Máquina
INTERFASE | PARTICIPANTES | FUNCIÓN
Joystick | Usuario ↔ ESP32 | Entrada directa del usuario para manipular la plataforma.
Pantalla TFT SPI | ESP32 ↔ Usuario | Visualización de variables, estado del sistema, resultados
del control.
Botón físico | Usuario ↔ Sistema | Control directo de encendido/apagado.

En concordancia con los principios, se definieron los flujos de información que intervienen en la comunicación entre el usuario y el sistema, categorizados según su naturaleza: información suministrada y visualizada.

Tabla 18.
Información que debe proporcionar el usuario
ACCIÓN | MEDIO | PROPÓSITO
Seleccionar modo de
control | Pantalla táctil Y joystick | Definir el algoritmo de
control a usar
Encender / Apagar el
sistema | Botón físico o interfaz HMI | Activar o suspender la
operación del sistema
Ajustar manualmente la
posición de cada motor
(X, Y, Z)

Joystick / sliders / botones HMI

Control directo para
pruebas o calibración

Navegar entre menús y
pantallas | Joystick - interfaz táctil | Acceso a distintas
funcionalidades

Confirmar cambios o
selecciones | Botón virtual o físico

Validar acciones como
modo de control o retorno
al menú

Tabla 19.
Información que el usuario debe ver
INFORMACIÓN | PANTALLA | PROPÓSITO
Título del proyecto y estado (Apagado) | Pantalla de inicio/apagado | Confirmar que el sistema está en modo seguro
Menú principal | Pantalla de menú | Navegación clara por funciones disponibles
Modo de control actual activo | Pantalla de método de control | Saber qué algoritmo está en uso
Datos de sensores: encoders y touch | Pantalla de variables/datos | Monitorear el estado del sistema en tiempo real
Posición de la bola (X, Y, Z) | Pantalla de gráficas | Observar comportamiento dinámico
Gráfica de la salida del sensor touch | Pantalla de gráficas | Análisis visual del sistema
Indicadores de retroalimentación (opcional) | Cualquier pantalla | Información de éxito o error en comandos

Finalmente, se presenta la interfaz de usuario (GUI), detallando las pantallas con las que el usuario interactúa durante la navegación entre los menús.

Tabla 20.
GUI
PANTALLA | FIGURA | PANTALLA | FIGURA | PANTALLA | FIGURA
Inicio | | Datos variables | | Formas
Menú principal | | Datos encoder motores | | Modo manual
Métodos de control | | Mapa de detección | | Diagrama Posición VS Tiempo
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

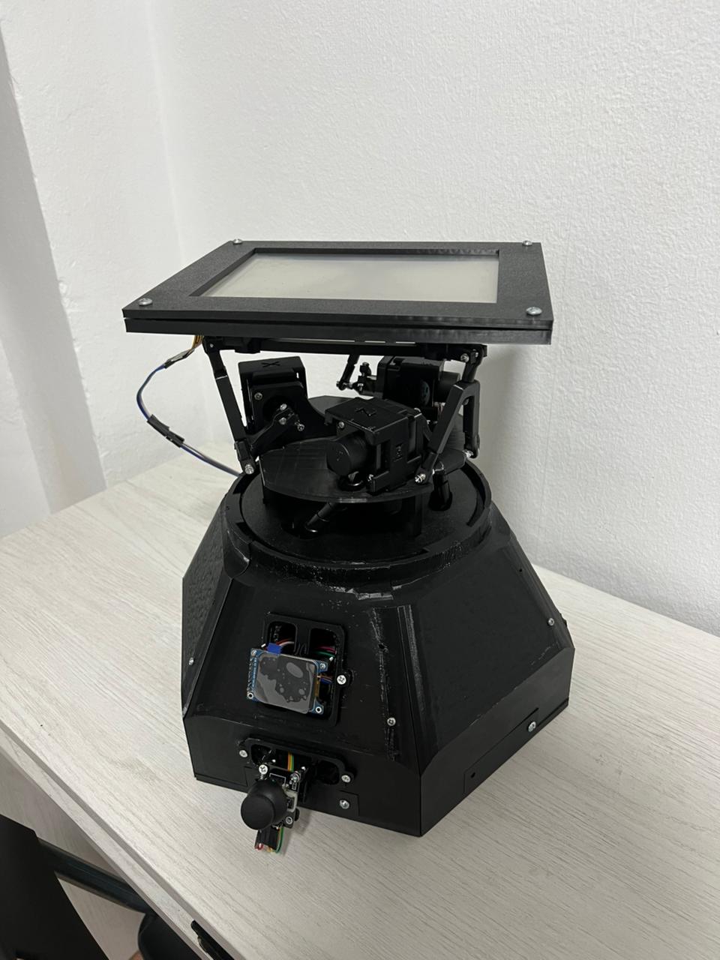
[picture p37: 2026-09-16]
media/images/tesisens.jpg

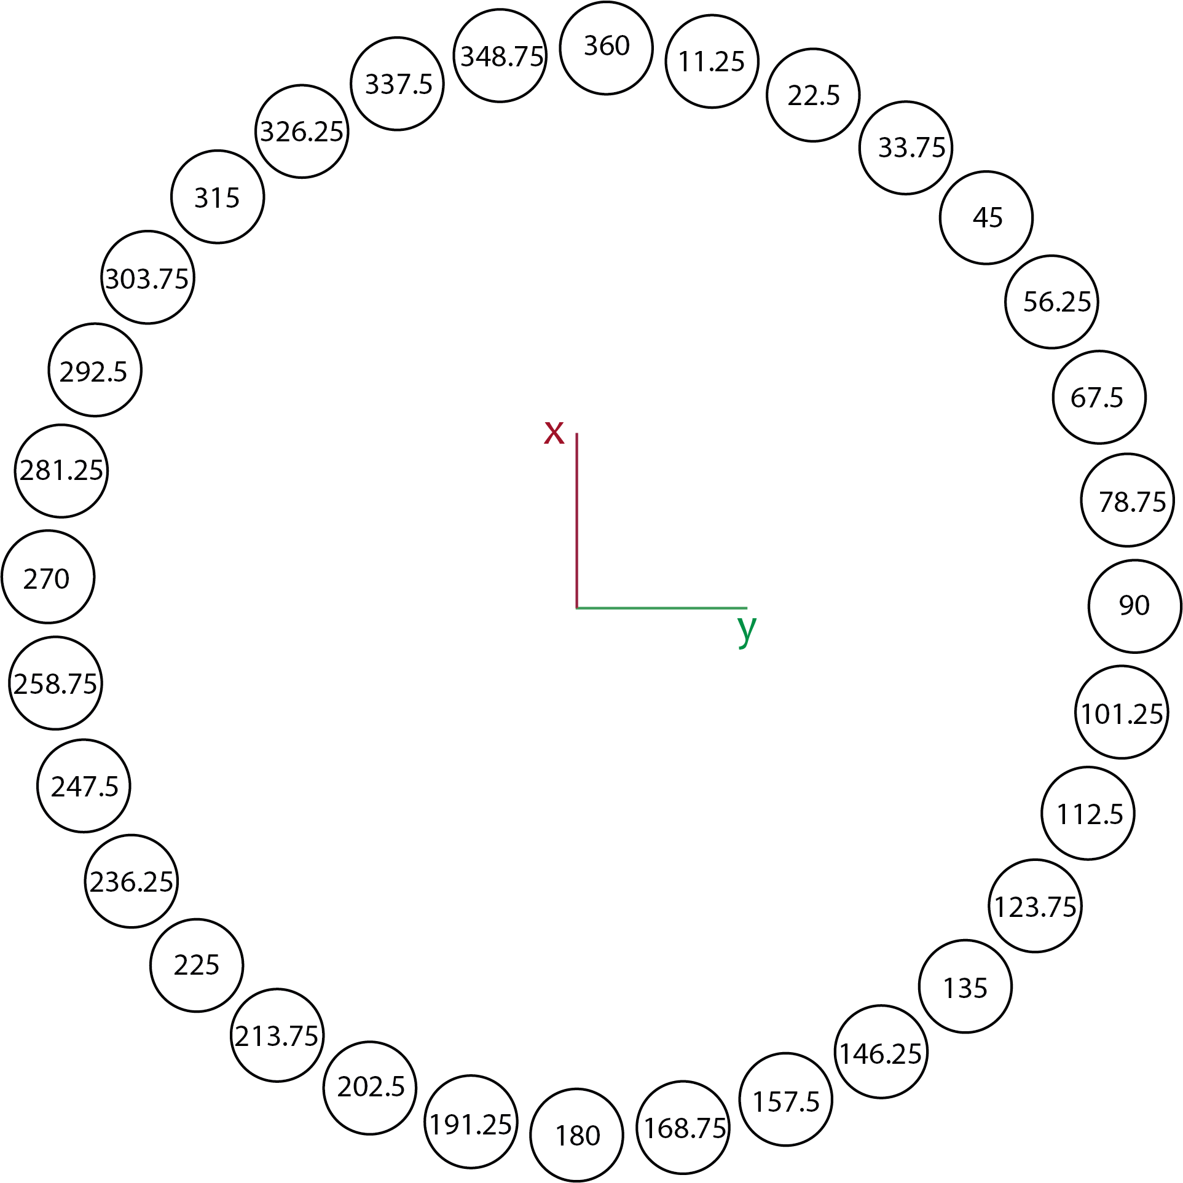
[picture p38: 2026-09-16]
docs/diagrams/network/Anillo.png

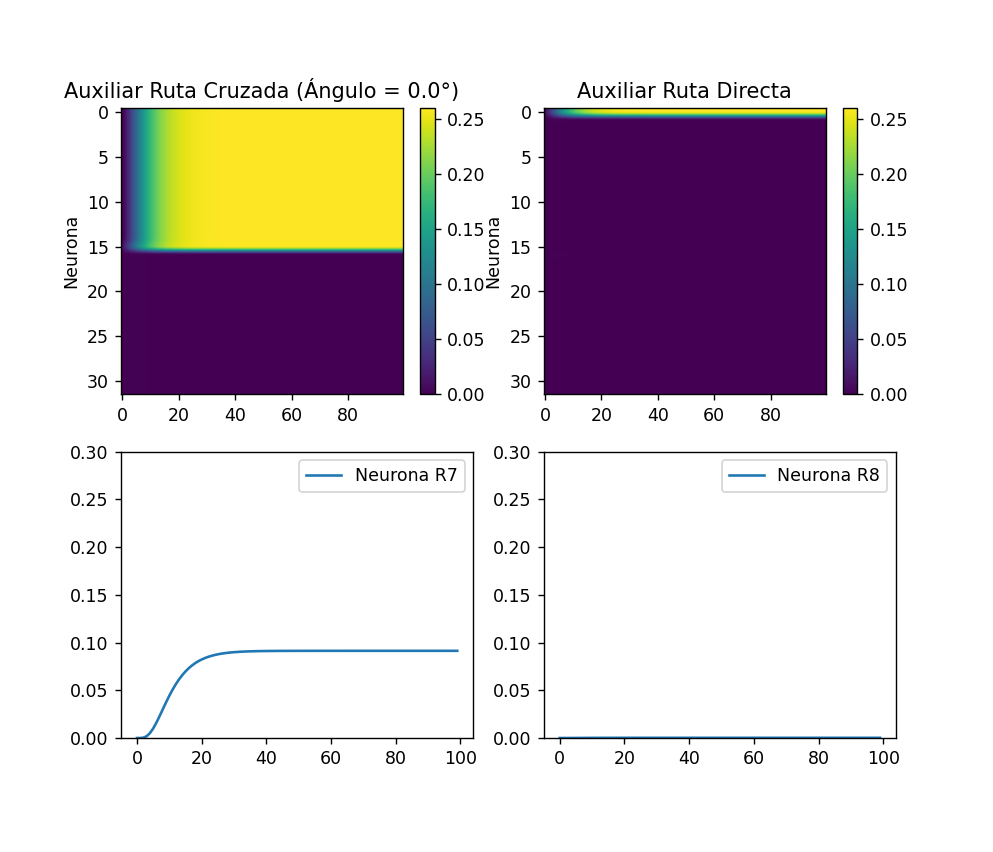
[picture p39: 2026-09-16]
docs/diagrams/network/red 0 grados.png

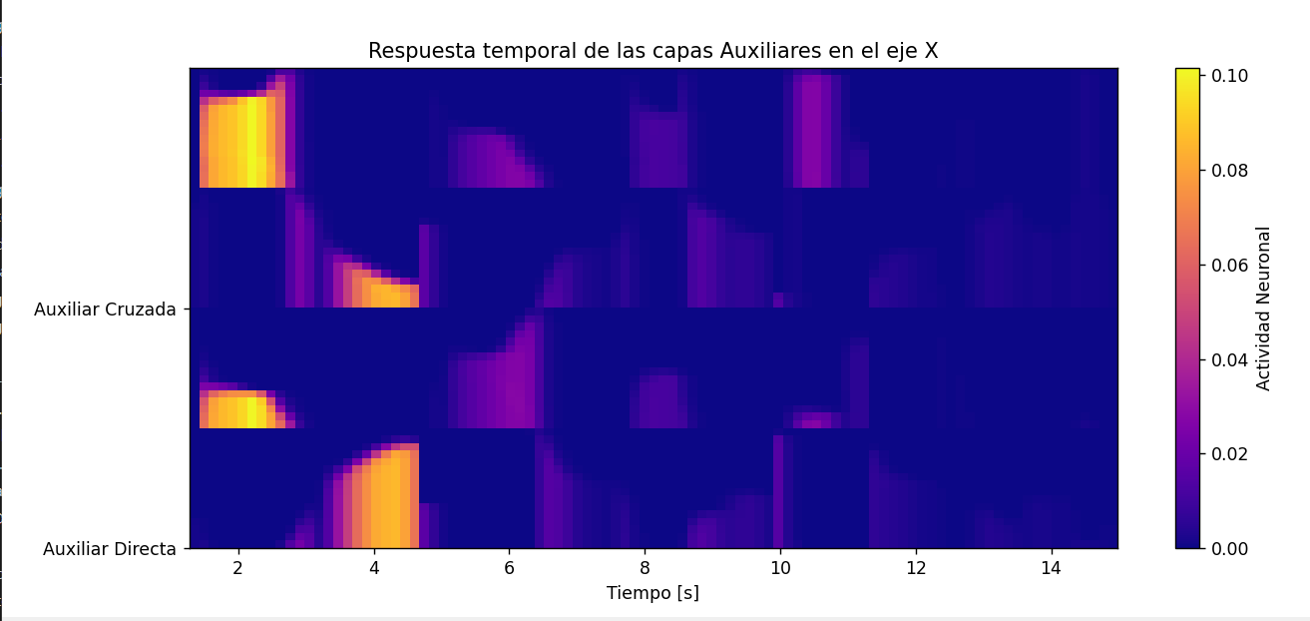
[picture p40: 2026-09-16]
docs/diagrams/network/AuxiliarXRED.png

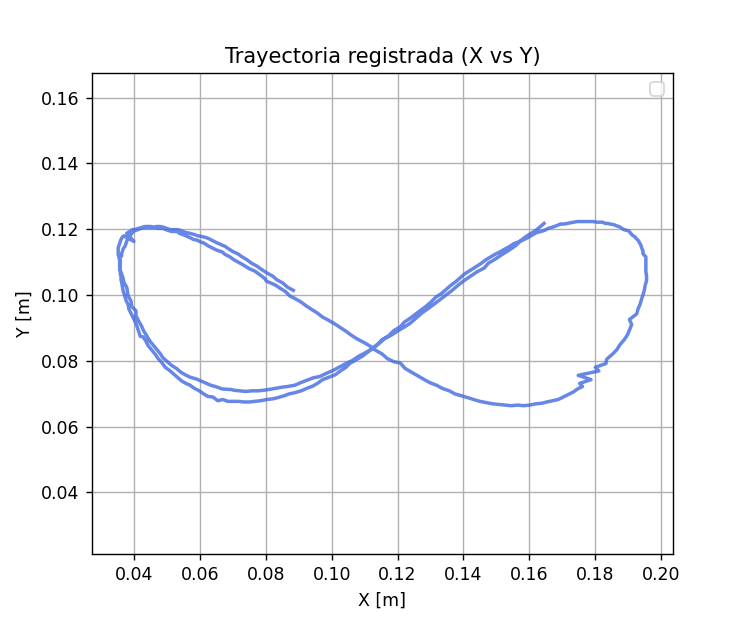
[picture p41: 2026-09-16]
docs/diagrams/seguidor/InfinitoXvsY.png

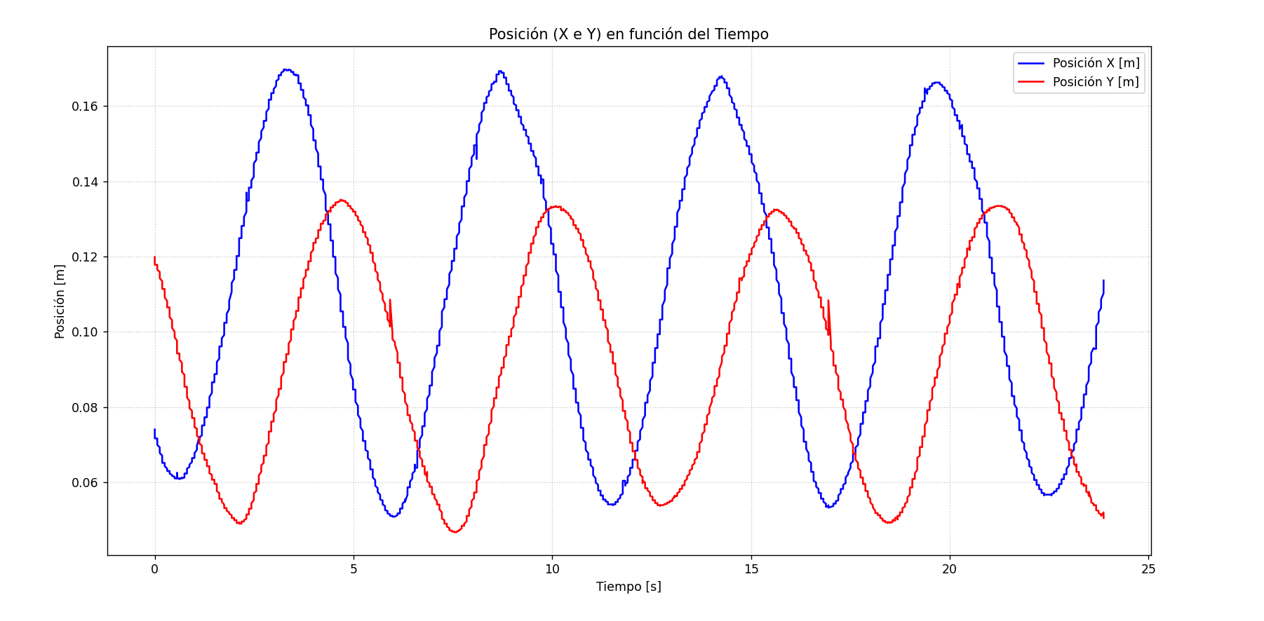
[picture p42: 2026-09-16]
docs/diagrams/seguidor/ElipseXYTime.png

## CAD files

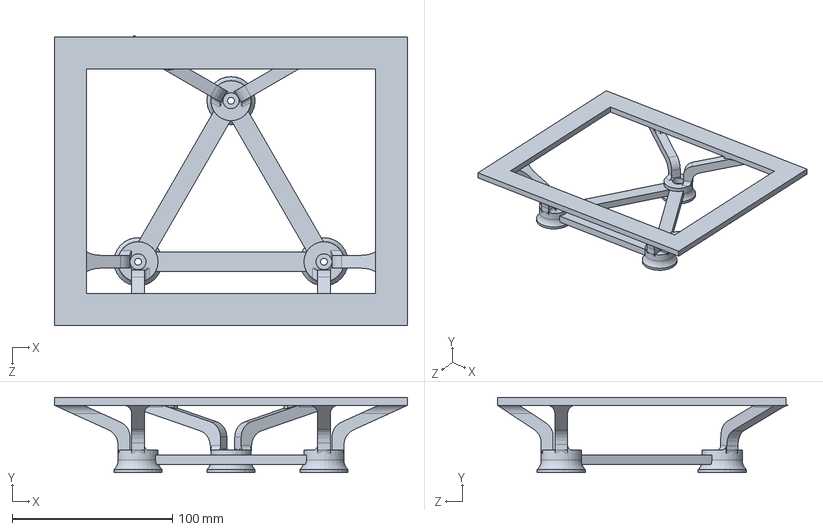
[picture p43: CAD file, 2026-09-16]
cad/parts/Soporte_Sensor.SLDPRT
220.0 x 47.0 x 180.9 mm

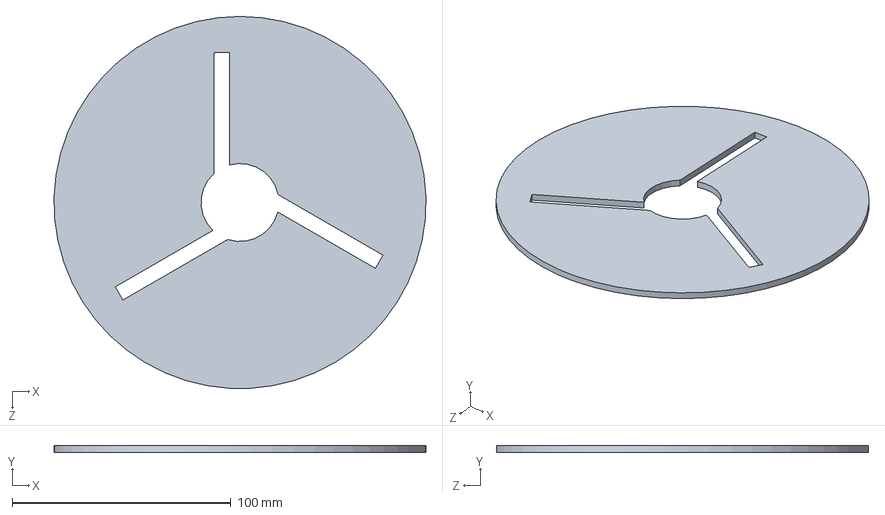
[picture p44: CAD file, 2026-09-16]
cad/parts/Tapa_Cilindro.SLDPRT
169.9 x 3.00 x 170.0 mm

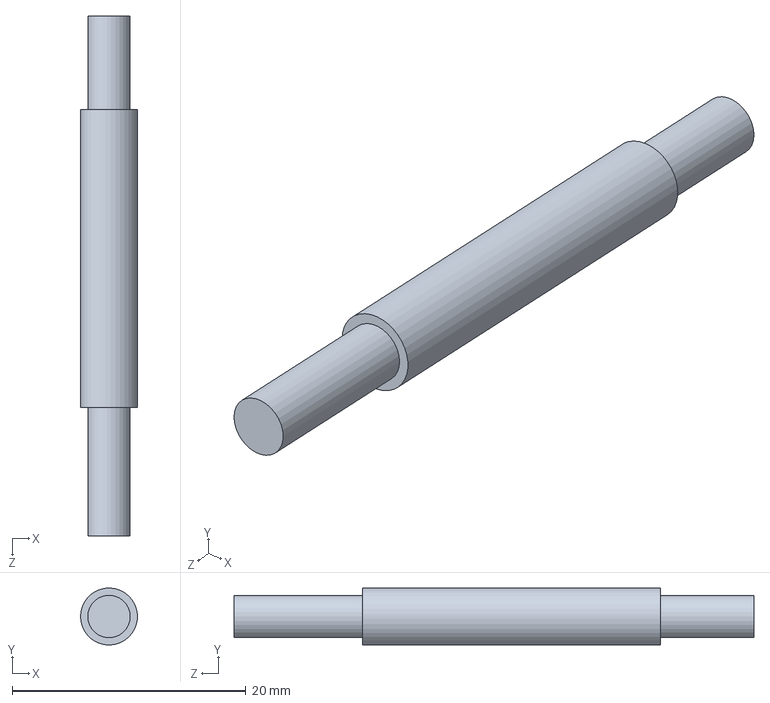
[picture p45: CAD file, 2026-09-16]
cad/parts/GraphiteRed.SLDPRT
4.88 x 4.87 x 44.5 mm

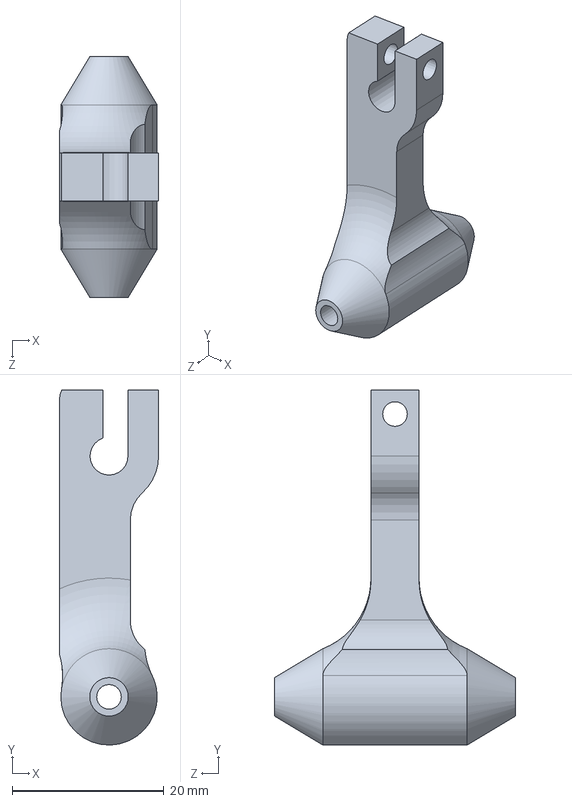
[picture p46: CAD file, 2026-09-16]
cad/parts/armRedi1_2022 (1).SLDPRT
13.1 x 46.8 x 31.8 mm

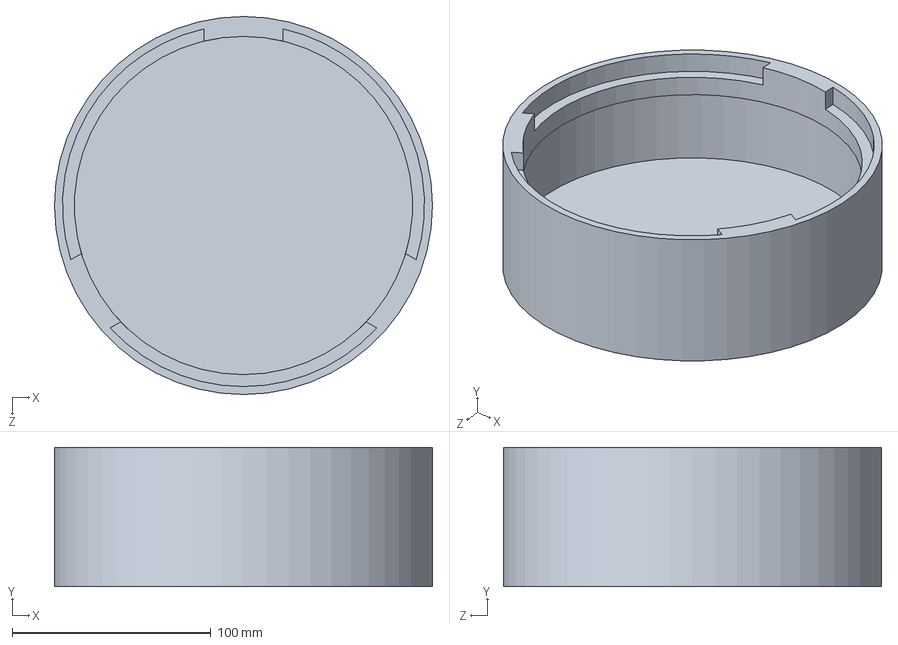
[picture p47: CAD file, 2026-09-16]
cad/parts/Cilindro_principal.SLDPRT
190.0 x 70.0 x 190.0 mm

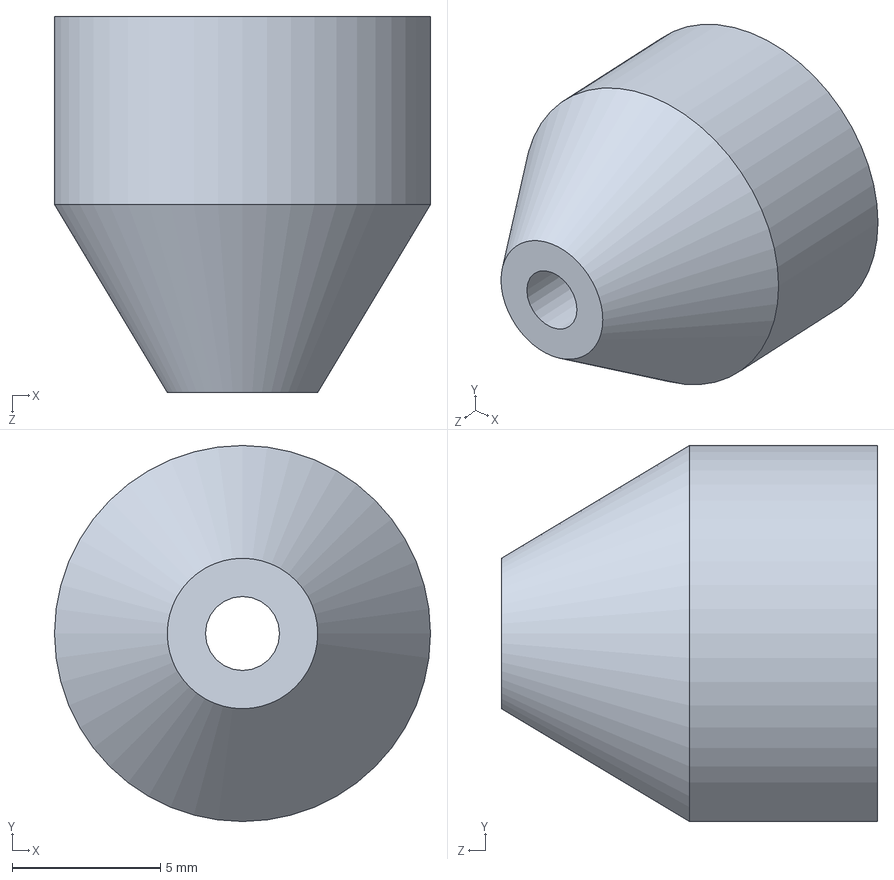
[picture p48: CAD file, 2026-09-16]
cad/parts/cone.sldprt
12.7 x 12.7 x 12.7 mm

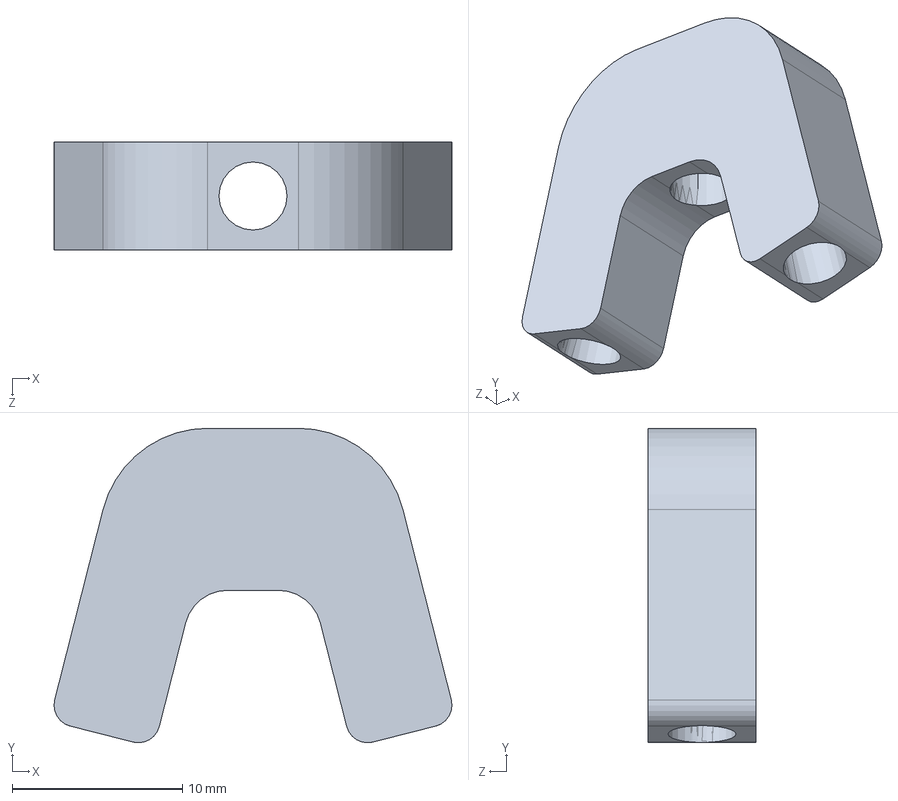
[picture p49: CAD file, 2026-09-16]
cad/parts/arm Y_new.SLDPRT
23.4 x 18.5 x 6.35 mm

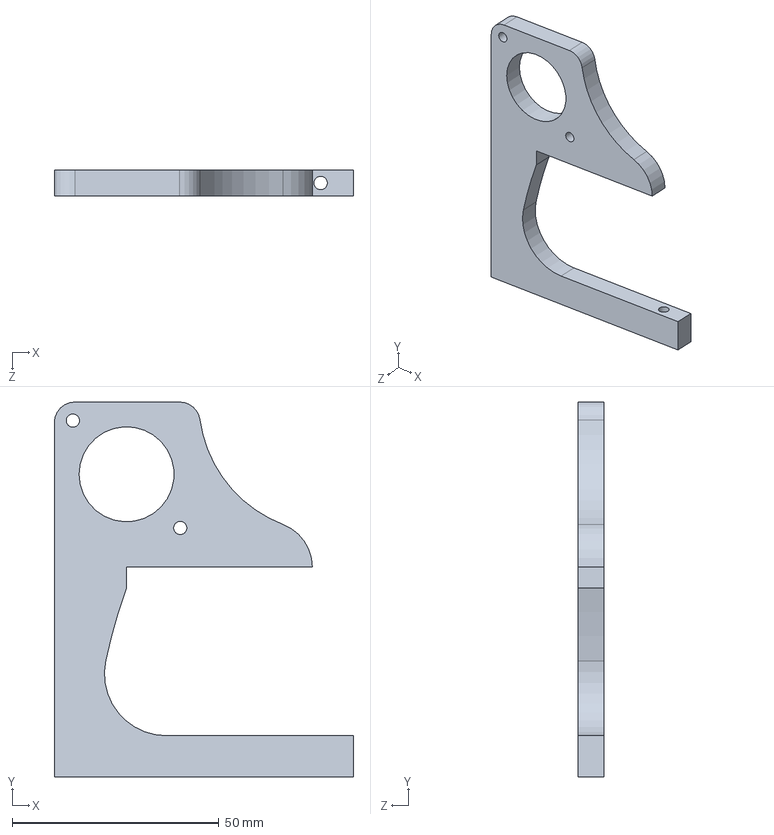
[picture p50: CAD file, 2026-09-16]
cad/parts/Arm_Motor.SLDPRT
72.5 x 90.8 x 6.35 mm

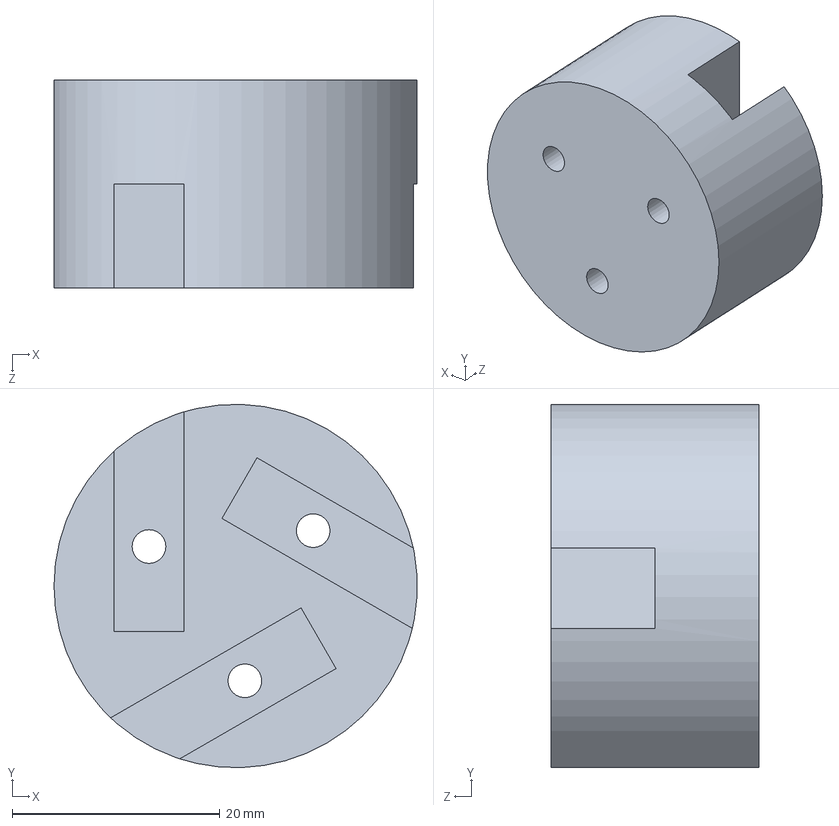
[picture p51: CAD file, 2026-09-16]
cad/parts/UnionArmMotorRed.SLDPRT
35.0 x 35.0 x 20.0 mm

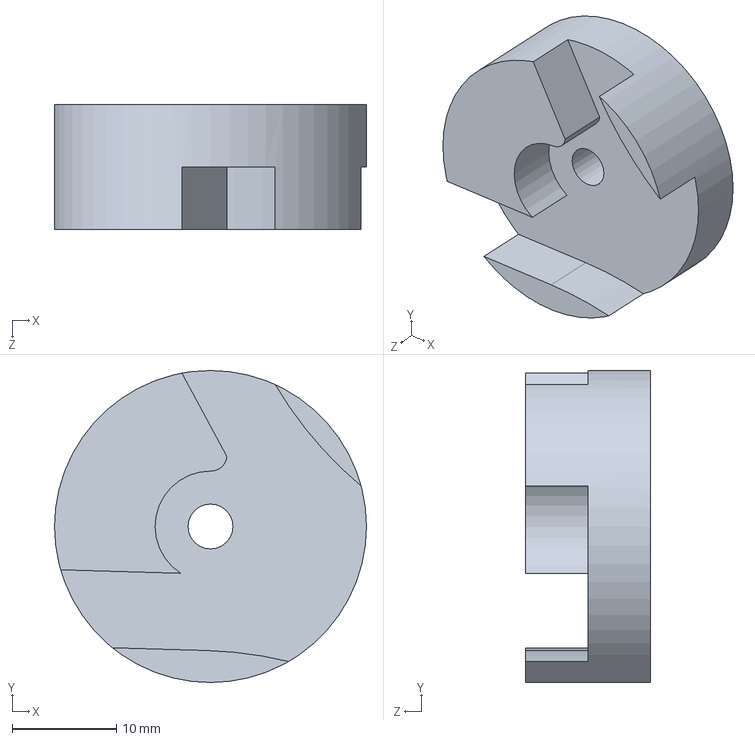
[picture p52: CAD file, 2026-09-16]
cad/parts/UnionTopDiskRed.SLDPRT
30.0 x 30.0 x 12.0 mm

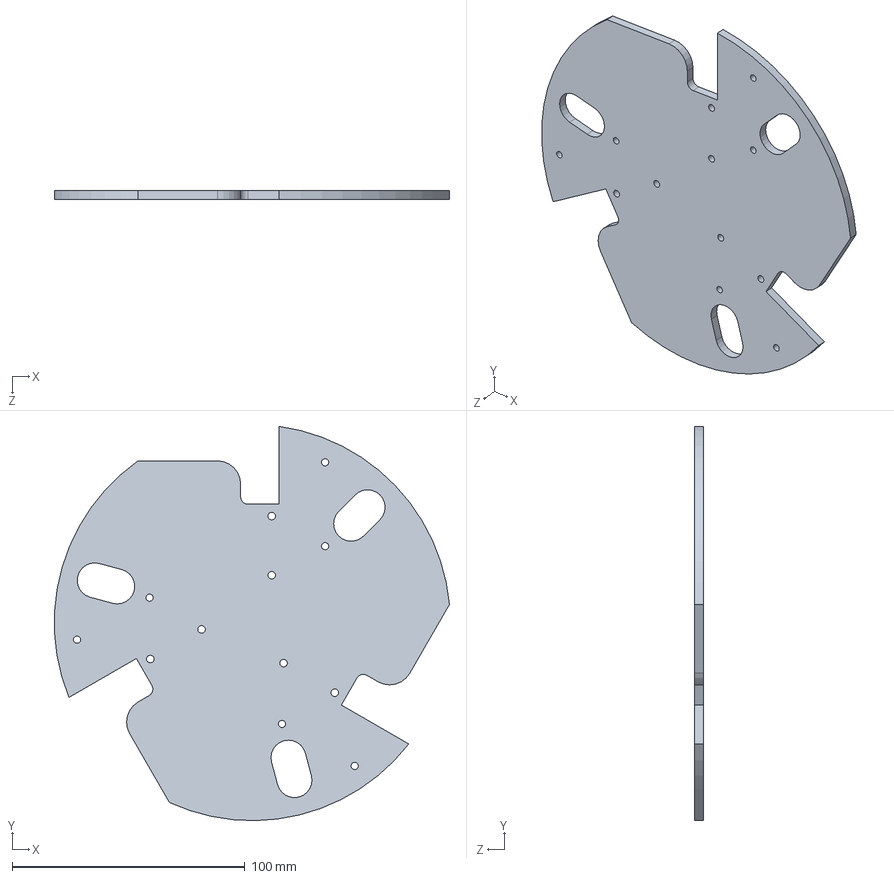
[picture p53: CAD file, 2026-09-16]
cad/parts/Disk_P.SLDPRT
169.5 x 169.2 x 4.00 mm

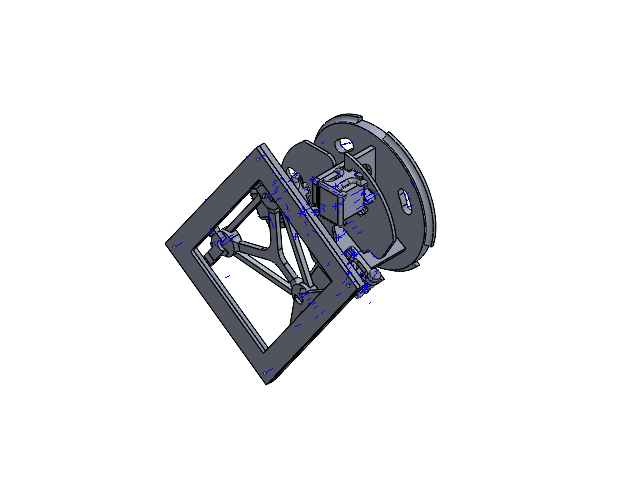
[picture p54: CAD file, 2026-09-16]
cad/assembly/Ensamblaje_Rediseño_Tesis.SLDASM
Disk_P
Arm_Motor x 3
UnionArmMotorRed
nema-14 x 3
Soporte_Motor x 3
TopDiskRed x 3
Pieza3^Ensamblaje_Rediseño_Tesis
armRedi1_2022 (1)
Traxxas2Red
TraxxazRed
Tapa_Cilindro2
Soporte_Sensor2
Tapa_Sensor2

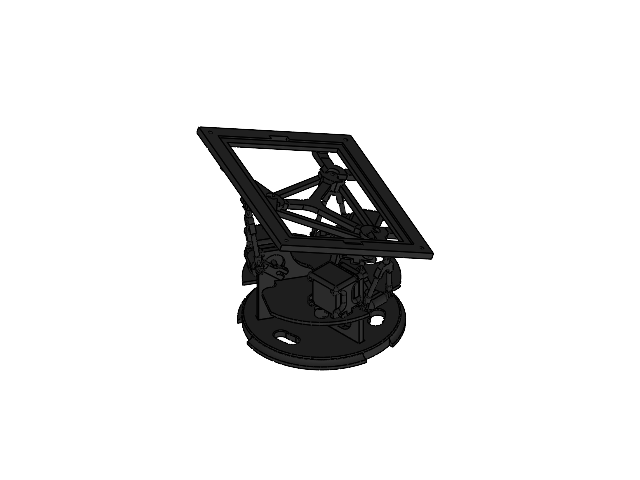
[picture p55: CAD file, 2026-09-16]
cad/assembly/SOLIDURDF.SLDASM
Disk_P
Arm_Motor x 3
nema-14 x 3
Tapa_Cilindro2
Soporte_Motor x 3
UnionArmMotorRed
armRedi1_2022 (1) x 3
Traxxas2Red x 9
Soporte_Sensor2
TopDiskRed x 3
GraphiteRed x 6
TraxxazRed x 9
arm Y_new x 3

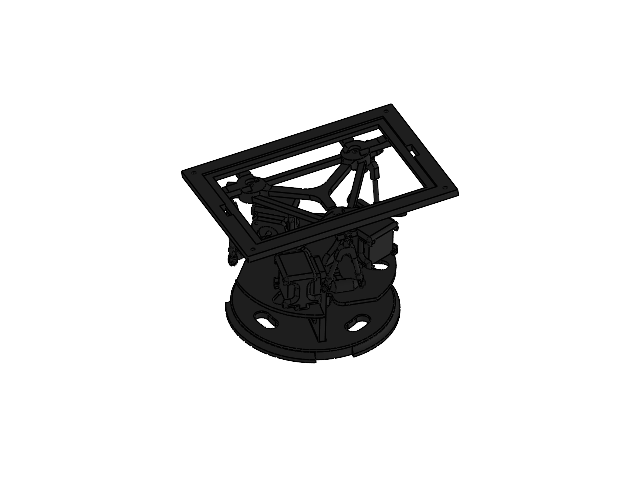
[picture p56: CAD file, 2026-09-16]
cad/assembly/Ensamblaje_3.SLDASM
Disk_P
Arm_Motor x 3
nema-14 x 3
Tapa_Cilindro2
armRedi1_2022 (1) x 3
Soporte_Sensor2
TopDiskRed x 3
GraphiteRed x 6
TraxxazRed x 9
Traxxas2Red x 9
arm Y_new x 3
Soporte_Motor x 3
UnionArmMotorRed

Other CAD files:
cad/parts/PlateURDF.SLDASM
cad/parts/link1.SLDASM
cad/parts/BaseURDF.SLDASM
cad/parts/link4.SLDASM
cad/parts/ArmYRed.SLDPRT
cad/parts/GraphiteRed - copia.SLDPRT
cad/parts/Soporte_Motor.SLDPRT
cad/parts/Soporte_Sensor2.SLDPRT
cad/parts/Tapa_Cilindro2.SLDPRT
cad/parts/Tapa_Sensor2.SLDPRT
cad/parts/TopDiskRed.SLDPRT
cad/parts/Traxxas2Red.SLDPRT
cad/parts/TraxxazRed.SLDPRT
cad/parts/nema-14.SLDPRT
cad/parts/traxxas_DeltaRed.SLDPRT

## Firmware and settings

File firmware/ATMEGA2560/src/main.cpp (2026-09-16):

#include <Encoder.h>
#include <SPI.h>
#include <avr/interrupt.h>
#include <avr/wdt.h>
/*
BALL & PLATE V2: Ahora se limita la posición de los motores y hay posibilidad de mirar latencias dentro del código

DESIRED POS: X = 650; Y = 650 aprox
Tanto como la pantalla como los encoders retornan valores enteros, uno long y otro int
*/

volatile bool stepEnableX = false;
volatile bool stepEnableY = false;
volatile bool stepEnableZ = false;  

const float TOLX = 0.4;
const float TOLY = 0.4;
const float TOLZ = 0.4;

const int Max_Vel = 5000; // Velocidad máxima en pasos por segundo (aprox 8000)
const int Min_Vel = 130; //130



// --- PID ---

/* 
//PID LENTO tol 0.5 all filters max vel 3k
float Kp = 35;
float Ki = 20;
float Kd = 1;
*/

/*
//PID MEDIO tol 0.5 all filters max vel 3k
float Kp = 400;
float Ki = 20;
float Kd = 2;
*/

//PID RAPIDO tol 0.5 all filters max vel 6k
// float Kp = 1000;
// float Ki = 20;
// float Kd = 5;


float Kp = 800;
float Ki = 10;
float Kd = 3;

float errorPrevX = 0, errorPrevY = 0, errorPrevZ = 0;
float integralX = 0, integralY = 0, integralZ = 0;


#define MOTORES_HABILITADOS 1
#define TIMER2ACT 0
#define USINGMACROS 1

// === SPI Estructuras ===
struct Angulos {
    float angX;
    float angY;
    float angZ;
    int16_t apagado;  
    int16_t KpMotor; 
};

struct Respuesta {
    int16_t touchX;
    int16_t touchY;
    float encoderX;
    float encoderY;
    float encoderZ;
  };

volatile Respuesta respuesta;
volatile Angulos datosRecibidos;

volatile int KpMotor;
volatile int apagado = 1;

volatile bool datoCompleto = false;
volatile byte* datos_ptr = (byte*)&datosRecibidos;
volatile size_t indice = 0;

volatile byte* respuesta_ptr = (byte*)&respuesta;
volatile size_t respuesta_indice = 0;

const byte START_BYTE = 0xA5;
const byte READY_BYTE = 0xAA;
volatile bool esperandoInicio = true;
volatile bool ready_to_send = false;

//Angulos recibidos de la ESP
volatile float targetX = 0;
volatile float targetY = 0;
volatile float targetZ = 0;


// =================== Pines motores ===================
#define dirPinX     55
#define stepPinX    54
#define enablePinX  38

#define dirPinY     61
#define stepPinY    60
#define enablePinY  56

#define dirPinZ     48
#define stepPinZ    46
#define enablePinZ  62

//MACROS --------------------------
// === MOTOR X ===
#define DIRX_PORT  PORTF
#define DIRX_BIT   PF1    // pin 55
#define STEPX_PORT PORTF
#define STEPX_BIT  PF0    // pin 54
#define ENX_PORT   PORTD
#define ENX_BIT    PD7    // pin 38

// === MOTOR Y ===
#define DIRY_PORT  PORTF
#define DIRY_BIT   PF7    // pin 61
#define STEPY_PORT PORTF
#define STEPY_BIT  PF6    // pin 60
#define ENY_PORT   PORTF
#define ENY_BIT    PF2    // pin 56

// === MOTOR Z ===
#define DIRZ_PORT  PORTL
#define DIRZ_BIT   PL1    // pin 48
#define STEPZ_PORT PORTL
#define STEPZ_BIT  PL3    // pin 46
#define ENZ_PORT   PORTK
#define ENZ_BIT    PK0    // pin 62


// =================== Variables SPI ===================

volatile byte bufferSPI[sizeof(Angulos)];
volatile size_t idxSPI = 0;
volatile bool spi_interrupted = false;


// === Encoders ===
// Motor X: D2 y D3
Encoder encoderX(2, 3);

// Motor Y: D18 y D19
Encoder encoderY(18, 19);

// Motor Z: D20 y D21 (NO mover estos pines)
Encoder encoderZ(20, 21);

// =================== Touchscreen (4 hilos) =================== (a10a11 no, a5a12no) 10c12 5c11 (11,12 lorh)
// #define XP A10 //A10, A11, A12, A5 
// #define XM A12
// #define YP A5 //No importa
// #define YM A11 //No importa
/*
Blanco: A11
Gris:   A12
Morado: A10
Azul:   A5
Pares:
A5,A12
A10,A11
*/

#define XP A5 
#define XM A12
#define YP A10 
#define YM A11 

// =================== Variables ===================
int touchX = 0, touchY = 0;

volatile float posX = 0, posY = 0, posZ = 0;
volatile bool dirX,dirY,dirZ; //true sube, false baja
volatile bool touch = false;


void configurarTimersMotores() {


    //OCR1A = 15999;          // (16 MHz) / (1 prescaler) * tiempo → 16k = 1ms
  //OCR1A = 7999; // 0.5ms
  //OCR1A = 3999; // 0.25ms

  cli(); // Desactivar interrupciones globales mientras se configuran

  // === Timer1 - Motor X ===
  TCCR1A = 0;
  TCCR1B = 0;
  TCNT1 = 0;
  OCR1A = 3500; // 0.375 ms aprox
  TCCR1B |= (1 << WGM12); // Modo CTC
  TCCR1B |= (1 << CS10);  // Prescaler 1
  TIMSK1 |= (1 << OCIE1A); // Habilita interrupción

  // === Timer3 - Motor Y ===
  TCCR3A = 0;
  TCCR3B = 0;
  TCNT3 = 0;
  OCR3A = 3500;
  TCCR3B |= (1 << WGM32);
  TCCR3B |= (1 << CS30);
  TIMSK3 |= (1 << OCIE3A);

  // === Timer4 - Motor Z ===
  TCCR4A = 0;
  TCCR4B = 0;
  TCNT4 = 0;
  OCR4A = 3500;
  TCCR4B |= (1 << WGM42);
  TCCR4B |= (1 << CS40);
  TIMSK4 |= (1 << OCIE4A);

  sei(); // Reactivar interrupciones globales
}



void setup() {

  Serial.begin(115200);


  pinMode(dirPinX, OUTPUT);
  pinMode(stepPinX, OUTPUT);
  pinMode(enablePinX, OUTPUT);

  pinMode(dirPinY, OUTPUT);
  pinMode(stepPinY, OUTPUT);
  pinMode(enablePinY, OUTPUT);

  pinMode(dirPinZ, OUTPUT);
  pinMode(stepPinZ, OUTPUT);
  pinMode(enablePinZ, OUTPUT);
  

  #if MOTORES_HABILITADOS
  digitalWrite(enablePinX, LOW); // Habilitar motor (LOW normalmente lo habilita)
  digitalWrite(enablePinY, LOW);
  digitalWrite(enablePinZ, LOW);
  #else
  digitalWrite(enablePinX, HIGH); // Habilitar motor (LOW normalmente lo habilita)
  digitalWrite(enablePinY, HIGH);
  digitalWrite(enablePinZ, HIGH);
  #endif

  digitalWrite(dirPinX, HIGH); // o LOW según dirección deseada
  digitalWrite(dirPinY, HIGH);
  digitalWrite(dirPinZ, HIGH);
  
  dirX = true, dirY = true, dirZ = true;


  #if TIMER2ACT
  // Timer2: interrupción cada 5 ms (aprox 200 Hz)
  TCCR2A = 0;
  TCCR2B = 0;
  TCNT2 = 0;

  // Modo CTC (Clear Timer on Compare Match)
  OCR2A = 124; // (16 MHz / (64 * 200)) - 1 = 124
  
  TCCR2A |= (1 << WGM21);
  // Prescaler 64
  TCCR2B |= (1 << CS22);  // 64 prescaler
  TIMSK2 |= (1 << OCIE2A);  // Habilita interrupción
  #endif


  configurarTimersMotores();

  

  //-------- PROTOCOLO SPI ----------------
  // SPI esclavo
  pinMode(MISO, OUTPUT);
  SPCR |= _BV(SPE);
  SPI.attachInterrupt();
  SPDR = 0x00;


}


float encoderToDegrees(long counts) {
  // Ticks por revolucion = 300 * 4 = 1200
  // grados = encoder * (360/1200) = encoder * 0.3
  return counts * 0.3;
}


// ==================================================== M O T O R E S ===========================================000



// ---------- MOTOR X --------------

#if USINGMACROS

// --- ISR para motor X (Timer1) ---
ISR(TIMER1_COMPA_vect) {
  static bool flancoX = false;

  if (!stepEnableX) {
    // Si no hay movimiento deseado, aseguramos STEP en LOW
    STEPX_PORT &= ~(1 << STEPX_BIT);   // LOW
    flancoX = false;
    return;
  }

  if (flancoX) {
    // Flanco bajo STEP
    STEPX_PORT &= ~(1 << STEPX_BIT);   // LOW
  } else {
    // Antes del flanco alto fijamos la dirección
    if (dirX) DIRX_PORT |= (1 << DIRX_BIT);   // HIGH
    else      DIRX_PORT &= ~(1 << DIRX_BIT);  // LOW

    STEPX_PORT |= (1 << STEPX_BIT);           // HIGH
  }

  flancoX = !flancoX;
}

#else

ISR(TIMER1_COMPA_vect) {
  static bool flancoX = false;

  if (!stepEnableX) {   // si no hay que mover
    digitalWrite(stepPinX, LOW);
    flancoX = false;
    return;
  }

  if (flancoX) {
    digitalWrite(stepPinX, LOW);
  } else {
    // fijar dirección según bandera global
    digitalWrite(dirPinX, dirX ? HIGH : LOW);
    digitalWrite(stepPinX, HIGH);
  }
  flancoX = !flancoX;
}

#endif

// ---------- MOTOR Y --------------

#if USINGMACROS


// --- ISR para motor Y (Timer3) ---
ISR(TIMER3_COMPA_vect) {
  static bool flancoY = false;

  if (!stepEnableY) {
    // Si no hay movimiento deseado, aseguramos STEP en LOW
    STEPY_PORT &= ~(1 << STEPY_BIT);   // LOW
    flancoY = false;
    return;
  }

  if (flancoY) {
    // Flanco bajo STEP
    STEPY_PORT &= ~(1 << STEPY_BIT);   // LOW
  } else {
    // Antes del flanco alto fijamos la dirección
    if (dirY) DIRY_PORT |= (1 << DIRY_BIT);   // HIGH
    else      DIRY_PORT &= ~(1 << DIRY_BIT);  // LOW

    STEPY_PORT |= (1 << STEPY_BIT);           // HIGH
  }

  flancoY = !flancoY;
}

#else

ISR(TIMER3_COMPA_vect) {
  static bool flancoY = false;

  if (!stepEnableY) {
    digitalWrite(stepPinY, LOW);
    flancoY = false;
    return;
  }

  if (flancoY) {
    digitalWrite(stepPinY, LOW);
  } else {
    digitalWrite(dirPinY, dirY ? HIGH : LOW);
    digitalWrite(stepPinY, HIGH);
  }
  flancoY = !flancoY;
}

#endif

// ---------- MOTOR Z --------------

#if USINGMACROS

ISR(TIMER4_COMPA_vect) {
  static bool flancoZ = false;

  if (!stepEnableZ) {
    // Si no hay movimiento deseado, aseguramos STEP en LOW
    STEPZ_PORT &= ~(1 << STEPZ_BIT);   // LOW
    flancoZ = false;
    return;
  }

  if (flancoZ) {
    // Flanco bajo STEP
    STEPZ_PORT &= ~(1 << STEPZ_BIT);   // LOW
  } else {
    // Antes del flanco alto fijamos la dirección
    if (dirZ) DIRZ_PORT |= (1 << DIRZ_BIT);   // HIGH
    else      DIRZ_PORT &= ~(1 << DIRZ_BIT);  // LOW

    STEPZ_PORT |= (1 << STEPZ_BIT);           // HIGH
  }

  flancoZ = !flancoZ;
}



#else
ISR(TIMER4_COMPA_vect) {
  static bool flancoZ = false;
  if (!stepEnableZ) {
    // si no hay movimiento deseado, asegúrate de poner STEP en LOW
    digitalWrite(stepPinZ, LOW);
    flancoZ = false;
    return;
  }
  if (flancoZ) {
    // Bajar STEP
    digitalWrite(stepPinZ, LOW);
  } else {
    // Antes del flanco alto fijamos la dirección
    digitalWrite(dirPinZ, dirZ ? HIGH : LOW);
    digitalWrite(stepPinZ, HIGH);
  }
  flancoZ = !flancoZ;
}

#endif

// =============================== SPI ISR ====================

ISR(SPI_STC_vect) {
  byte c = SPDR;
  static int contadorErr = 0; 
  if (esperandoInicio) {
    if (c == START_BYTE) {
      esperandoInicio = false;
      indice = 0;
    }
  } else if (indice < sizeof(Angulos)) {
    datos_ptr[indice++] = c;
    if (indice >= sizeof(Angulos)) {
      datoCompleto = true;
      esperandoInicio = true;
      ready_to_send = true;
      respuesta_indice = 0;
      SPDR = READY_BYTE;
      return;
    }
  }
  else contadorErr++;

  if (contadorErr > 100){
    datoCompleto = false;
    ready_to_send = false;
    esperandoInicio = true;

  }

  if (ready_to_send) {
    respuesta_indice++;
    if (respuesta_indice <= sizeof(Respuesta)) {
      SPDR = respuesta_ptr[respuesta_indice - 1];
    } else {
      ready_to_send = false;
      SPDR = 0x00;
    }
  } else {
    SPDR = 0x00;
  }
}



// =========================  T O U C H S C R E E N =================================================

const int N = 4; //Numero de lecturas anteriores
int lastX[N] = {0}, lastY[N] = {0};
int idx = 0;
bool historialInicializado = false;

void detect_touch() {

  // Configurar para detección de contacto
  pinMode(XP, INPUT_PULLUP); // Línea que leeremos
  pinMode(XM, INPUT_PULLUP);
  pinMode(YP, INPUT);        // Línea flotante
  pinMode(YM, OUTPUT);
  digitalWrite(YM, LOW);     // Poner YM a GND

  touch = digitalRead(XP) == LOW;

}

int media(int* arr) {
  long suma = 0;
  for (int i = 0; i < N; i++) suma += arr[i];
  return suma / N;
}

void touchscreen() {
  static uint8_t estado = 0;
  static unsigned long t_espera = 0;
  static int lecturaX = 0, lecturaY = 0;

  switch (estado) {
    case 0:
      detect_touch();

      // if (!touch) {
      //   touchX = 500;
      //   touchY = 500;
      //   return;
      // }

      // Preparar lectura eje Y
      pinMode(YP, INPUT);
      pinMode(YM, INPUT);
      pinMode(XP, OUTPUT); digitalWrite(XP, HIGH);
      pinMode(XM, OUTPUT); digitalWrite(XM, LOW);
      t_espera = millis();
      estado = 1;
      break;

    case 1:
      if (millis() - t_espera >= 10) {
        lecturaY = analogRead(YP);

        // Preparar lectura eje X
        pinMode(XP, INPUT);
        pinMode(XM, INPUT);
        pinMode(YP, OUTPUT); digitalWrite(YP, HIGH);
        pinMode(YM, OUTPUT); digitalWrite(YM, LOW);
        t_espera = millis();
        estado = 2;
      }
      break;

    case 2:
      if (millis() - t_espera >= 10) {
        lecturaX = analogRead(XP);
        estado = 0;  // Reiniciar para la siguiente lectura

        // -------------------- Filtro de lecturas atípicas -----------------------
        const int UMBRAL = 80; //AUMENTA --> Admite más lecturas 170 ori
        int promX = media(lastX);
        int promY = media(lastY);
        bool saltoDesdeCero = (promX < 10 && promY < 10 && lecturaX > 10 && lecturaY > 10);
        bool lecturaValida = 
          (abs(lecturaX - promX) < UMBRAL) && 
          (abs(lecturaY - promY) < UMBRAL);

        if (!historialInicializado) {
          for (int i = 0; i < N; i++) {
            lastX[i] = lecturaX;
            lastY[i] = lecturaY;
          }
          historialInicializado = true;
          touchX = lecturaX;
          touchY = lecturaY;
        } else if (lecturaValida || saltoDesdeCero) {
          touchX = lecturaX;
          touchY = lecturaY;
          lastX[idx] = lecturaX;
          lastY[idx] = lecturaY;
          idx = (idx + 1) % N;
        }
      }
      break;
  }
}


float map_output(float x, float in_min, float in_max, float out_min, float out_max) {
    if (x < in_min) x = in_min;
    if (x > in_max) x = in_max;
    return (x - in_min) * (out_max - out_min) / (in_max - in_min) + out_min;
}


float map_output_smooth(float x, float in_min, float in_max, float out_min, float out_max) {
    // normalizar 0..1
    if (x <= in_min) return out_min;
    if (x >= in_max) return out_max;
    float t = (x - in_min) / (in_max - in_min);
    // aplicar curva (t^2 para suavizar cerca de 0)
    float t2 = t * t;
    return out_min + t2 * (out_max - out_min);
}


float rate_limit(float prev, float target, float max_delta_per_sec, float dt) {
    float max_delta = max_delta_per_sec * dt;
    float delta = target - prev;
    if (delta > max_delta) delta = max_delta;
    if (delta < -max_delta) delta = -max_delta;
    return prev + delta;
}

float lowpass(float prev, float measured, float alpha) {
    return alpha * measured + (1.0f - alpha) * prev;
}

void loop() {

  touchscreen();

  // static unsigned long timedebug = 0;
  
  // if(millis() - timedebug > 1000){
  //   timedebug = millis();
  //   digitalWrite(LED_BUILTIN, !digitalRead(LED_BUILTIN));
  //   Serial.println("Hola conectado");
  // }
  
  //PRIMER FILTRO
  
  //static float targetFiltroX = 0, targetFiltroY = 0, targetFiltroZ = 0;
  static float lastTargetX = 0, lastTargetY = 0, lastTargetZ = 0;
  static float vel_prevX = 0, vel_prevY = 0, vel_prevZ = 0;
  const float alpha = 0.3;
  
  posX = encoderToDegrees(encoderX.read());
  posY = encoderToDegrees(encoderY.read());
  posZ = encoderToDegrees(encoderZ.read());


  if (datoCompleto) {
    
    respuesta.touchX = touchX;
    respuesta.touchY = touchY;
    respuesta.encoderX = posX;
    respuesta.encoderY = posY;
    respuesta.encoderZ = posZ;
    
    datoCompleto = false;
    
    apagado = datosRecibidos.apagado;
    KpMotor = datosRecibidos.KpMotor;
    
    targetX = datosRecibidos.angX;
    targetY = datosRecibidos.angY;
    targetZ = datosRecibidos.angZ;
    
  }

  Kp = (float)KpMotor;


  //LOGICA DE APAGADO
  if (apagado) {
    digitalWrite(enablePinX, HIGH);  // deshabilitar motores
    digitalWrite(enablePinY, HIGH);
    digitalWrite(enablePinZ, HIGH);
  } else {
    #if MOTORES_HABILITADOS
    digitalWrite(enablePinX, LOW);   // habilitar motores
    digitalWrite(enablePinY, LOW);
    digitalWrite(enablePinZ, LOW);
    #else
    digitalWrite(enablePinX, HIGH);  // deshabilitar motores
    digitalWrite(enablePinY, HIGH);
    digitalWrite(enablePinZ, HIGH);
    #endif
  }



  //PRIMER FILTRO
  //targetX = (1 - alpha) * targetX + alpha * targetX;
  //targetY = (1 - alpha) * targetY + alpha * targetY;
  //targetZ = (1 - alpha) * targetZ + alpha * targetZ;  

  targetX = lowpass(lastTargetX, targetX, alpha);
  targetY = lowpass(lastTargetY, targetY, alpha);
  targetZ = lowpass(lastTargetZ, targetZ, alpha);


  static unsigned long last = 0;
  const float pid_output_min = 0;
  const float pid_output_max = 6000; // ajustar según sea necesario

  if (millis() - last >= 10) {  // entre 5 y 50ms 
    last = millis();

    float dt = 0.02; //20ms
    // ============================= Motor X ============================
    //posX = encoderToDegrees(encoderX.read());
    if (posX < 0) posX = 0;

    float errorX = targetX - posX;

    integralX += errorX * dt;  // dt=2ms
    float derivativeX = (errorX - errorPrevX)/dt;
    float salidaX = Kp*errorX + Ki*integralX + Kd*derivativeX;
    errorPrevX = errorX;

    float velStepsX = map_output_smooth(fabs(salidaX), pid_output_min, pid_output_max, Min_Vel, Max_Vel);
    //float velStepsX = map_output(fabs(salidaX), pid_output_min, pid_output_max, Min_Vel, Max_Vel);
    if (velStepsX < Min_Vel) velStepsX = Min_Vel;  // seguridad

    velStepsX = rate_limit(vel_prevX, velStepsX, 2000.0f, dt);
    vel_prevX = velStepsX;


    //float velStepsX = fabs(salidaX);

    //if (velStepsX < Min_Vel) velStepsX = Min_Vel;
    //if (velStepsX > Max_Vel) velStepsX = Max_Vel;

    dirX = (salidaX > 0);
    stepEnableX = (abs(errorX) > TOLX);

    uint16_t ocrX = F_CPU / (2 * 1 * velStepsX);
    noInterrupts();
    OCR1A = ocrX;   // Timer1 controla motor X
    interrupts();


    // ================================== Motor Y ==============================
    //posY = encoderToDegrees(encoderY.read());
    if (posY < 0) posY = 0;

    float errorY = targetY - posY;

    integralY += errorY * dt;
    float derivativeY = (errorY - errorPrevY)/dt;
    float salidaY = Kp*errorY + Ki*integralY + Kd*derivativeY;
    errorPrevY = errorY;

    float velStepsY = map_output_smooth(fabs(salidaY), pid_output_min, pid_output_max, Min_Vel, Max_Vel);
    if (velStepsY < Min_Vel) velStepsY = Min_Vel;  // seguridad

    velStepsY = rate_limit(vel_prevY, velStepsY, 2000.0f, dt);
    vel_prevY = velStepsY;



    //float velStepsY = fabs(salidaY);
    //if (velStepsY < Min_Vel) velStepsY = Min_Vel;
    //if (velStepsY > Max_Vel) velStepsY = Max_Vel;

    dirY = (salidaY > 0);
    stepEnableY = (abs(errorY) > TOLY);

    uint16_t ocrY = F_CPU / (2 * 1 * velStepsY);
    noInterrupts();
    OCR3A = ocrY;   // Timer3 controla motor Y
    interrupts();


    // ============================ Motor Z =============================

    //posZ = encoderToDegrees(encoderZ.read());
    if (posZ < 0) posZ = 0;

    float errorZ = targetZ - posZ;

    integralZ += errorZ * dt;
    float derivativeZ = (errorZ - errorPrevZ)/dt;
    float salidaZ = Kp*errorZ + Ki*integralZ + Kd*derivativeZ;
    errorPrevZ = errorZ;

    float velStepsZ = map_output_smooth(fabs(salidaZ), pid_output_min, pid_output_max, Min_Vel, Max_Vel);
    if (velStepsZ < Min_Vel) velStepsZ = Min_Vel;  // seguridad

    velStepsZ = rate_limit(vel_prevZ, velStepsZ, 2000.0f, dt);
    vel_prevZ = velStepsZ;


    //float velStepsZ = fabs(salidaZ);
    //if (velStepsZ < Min_Vel) velStepsZ = Min_Vel;
    //if (velStepsZ > Max_Vel) velStepsZ = Max_Vel;
    
    
    dirZ = (salidaZ > 0);
    stepEnableZ = (abs(errorZ) > TOLZ);
    
    uint16_t ocrZ = F_CPU / (2 * 1 * velStepsZ);
    noInterrupts();
    OCR4A = ocrZ;   // Timer4 controla motor Z
    interrupts();



  }

  lastTargetX = targetX;
  lastTargetY = targetY;
  lastTargetZ = targetZ;


}

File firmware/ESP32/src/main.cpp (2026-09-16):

extern "C"{
    #include <stdio.h>
    #include <string.h>
    #include "freertos/FreeRTOS.h"
    #include "freertos/task.h"
    #include "freertos/timers.h" //timers (considerar hacerlos manuales)
    #include "driver/spi_master.h" //spi
    #include "esp_log.h" 
    #include "driver/adc.h" // joystick con driver/adc.h
    #include "driver/gpio.h" // Para el botón del joystick
    #include <math.h>
}

//------------------ DEBUG ----------------------
#define DEBUG_SPI 0
#define DEBUG_PANTALLA 0
#define DEBUG_RENDIMIENTO 0
#define DEBUG_CONTROL 0

//Estilos ------------------- [SOLO SELECCIONE UNO]
#define INTERFAZ_COLOR_AZUL 0
#define INTERFAZ_COLOR_ROJO 1
#define INTERFAZ_COLOR_MORADO 0


//SPI PINES
#define PIN_NUM_MISO 19
#define PIN_NUM_MOSI 23
#define PIN_NUM_CLK  18
#define PIN_NUM_CS   5

//Joystick pines
#define JOY_X_PIN 34  // Pin para VRX (Eje X)
#define JOY_Y_PIN 35  // Pin para VRY (Eje Y)
#define JOY_SW_PIN GPIO_NUM_33 // Pin para SW (botón)

//PANTALLA
#include <TFT_eSPI.h>
#include <lvgl.h>
#include <fondo.cpp>
#include <vector>
#include <cmath>
#include <algorithm>
#include <numeric> // Para std::accumulate (dot_product)

TFT_eSPI tft = TFT_eSPI();  // Usa el setup del archivo User_Setup.h

#include <InverseKinematics.h> // Inverse Kinematics


//LVGL ----------------------------------

static const uint16_t screenWidth = 280;
static const uint16_t screenHeight = 240;


static lv_disp_draw_buf_t draw_buf;
static lv_color_t buf1[screenWidth * 20];
static lv_color_t buf2[screenWidth * 20];
static lv_disp_drv_t disp_drv;


// --------------------------------------


static const char* TAG = "SPI_Master";

// Estructura de datos a enviar
typedef struct {
    float anguloX;
    float anguloY;
    float anguloZ;
    int16_t apagado; 
    int16_t KpMotor; 
} Angulos;

Angulos datosParaEnviar = {0, 0, 0, 1, 800};  // o valores iniciales

// Estructura de respuesta
typedef struct {
    int16_t touchX;
    int16_t touchY;
    float encoderX;
    float encoderY;
    float encoderZ;
} Respuesta;

Respuesta datos_display;

struct DatosIK {
    float nx;
    float ny;
    float hz;
    float IKX;
    float IKY;
    float IKZ;
};

DatosIK datosIK;


struct PIDState {
    float integral;
    float previous_error;
};

PIDState pidX = {0,0};
PIDState pidY = {0,0};

//Variables globales
spi_device_handle_t spi_com;
//X, Y, Z, apagado, varcontrol

// --------------------------------------  Pantalla -----------------------------------

// Comandos UI para la cola de mensajes
typedef enum {
    UI_CMD_NONE = 0,
    UI_CMD_NAVIGATE_UP,
    UI_CMD_NAVIGATE_DOWN,
    UI_CMD_NAVIGATE_LEFT,
    UI_CMD_NAVIGATE_RIGHT,
    UI_CMD_SELECT,
    UI_CMD_JOYSTICK_CENTER  
} ui_cmd_t;

typedef struct {
    ui_cmd_t cmd;
    // Puedes añadir más parámetros si es necesario
} ui_msg_t;


enum Pantalla {
    MENU_PRINCIPAL,
    METODO_CONTROL,
    MODO_MANUAL,
    DATOS_VARIABLES,
    GRAFICAS,
    CINEMATICAINVERSA,
    FORMAS,
    APAGADO,
    NUM_PANTALLAS
};
Pantalla pantalla_actual = MENU_PRINCIPAL;



//joystick values ----- 

int joystick_x  = 0;
int joystick_y  = 0;
bool boton_presionado = false;
bool boton_anterior = false;  // Nuevo: para detectar flanco

typedef enum {
    JOY_CENTER,
    JOY_UP,
    JOY_DOWN,
    JOY_LEFT,
    JOY_RIGHT
} joystick_direction_t;

joystick_direction_t joystick_pos; // global o estática


// -------------------- MENU --------------------fondo1

QueueHandle_t ui_msg_queue;
SemaphoreHandle_t xGuiSemaphore;
lv_obj_t *label;  // Global para modificarlo desde tareas

// MENU PRINCIPAL -------------------
lv_obj_t *menu_list;
lv_obj_t *btn_opciones[NUM_PANTALLAS-1];
int opcion_actual = 0;


lv_obj_t *btn_volver;

//ESTILOS --------------------------
static lv_style_t estilo_focused;
static lv_style_t estilo_default;
static lv_style_t spinbox_estilo_focused;
static lv_style_t spinbox_estilo_default;
static lv_style_t estilo_contenedor_oscuro;
static lv_style_t estilo_outline;

//METEODO DE CONTROL ------------------------
int metodo_control_sw = 0;
int forma_control_sw = 0;
lv_obj_t *btn_metctrl[4];
bool MotorInit = false;

//Datos Variables ------------------
lv_obj_t* label_encoder_x = nullptr;
lv_obj_t* label_encoder_y = nullptr;
lv_obj_t* label_encoder_z = nullptr;
lv_obj_t* label_touch_x = nullptr;
lv_obj_t* label_touch_y = nullptr;
lv_timer_t* timer_enc_touch = NULL;

//MODO MANUAL -------------
lv_obj_t* spinboxes[3];
lv_obj_t *btn_plus[3];
lv_obj_t *btn_minus[3];
int spinbox_index_actual = 0;

//GRAFICAS -------------
const int NUM_SUBMENUS = 2;
int submenu_actual = 0;
lv_obj_t * btn_prev;
lv_obj_t * btn_next;
lv_timer_t * chart_timer = nullptr;
lv_timer_t * circulo_timer = nullptr;
int opcion_actual2 = 0;

//CINEMATICA INVERSA
lv_obj_t* label_nx = nullptr;
lv_obj_t* label_ny = nullptr;
lv_obj_t* label_hz = nullptr;
lv_obj_t* label_output = nullptr;
lv_timer_t* timer_IK = NULL;

//-------------------------- PID --------------------------------------

Machine machine(2.0, 3.56820, 1.25259, 3.0286); //INVERSE KINEMATICS

//PID LENTO: 0.04,0.03,0.03,0.04,0.03,0.03
//PID MEDIO: 0.07,0.04,0.01,0.07,0.04,0.01
//PID RÁPIDO: 0.15,0.04,0.01,0.15,0.04,0.01
//PID MUY RÁPIDO: 0.09,0.04,0.06,0.09,0.04,0.06
//0.15,0.07,0.025,0.15,0.07,0.025
//0.2,0.05,0.009,0.2,0.05,0.009


// float Kpx = 0.15, Kix = 0.04, Kdx = 0.01;
// float Kpy = 0.15, Kiy = 0.04, Kdy = 0.01;

float Kpx = 0.15, Kix = 0.04, Kdx = 0.01;
float Kpy = 0.15, Kiy = 0.04, Kdy = 0.01;


float previous_error = 0;
float integral = 0;

//------------------------- SEGUIDOR CON OBSERVADOR ------------------------------------



// ==================== VARIABLES DEL ESTADO =====================
const double Ad[4][4] = {
    { 1.000000000000000, 0.010000000000000, 0.000350357142857, 0.000001167857143 },
    { 0.000000000000000, 1.000000000000000, 0.070071428571429, 0.000350357142857 },
    { 0.000000000000000, 0.000000000000000, 1.000000000000000, 0.010000000000000 },
    { 0.000000000000000, 0.000000000000000, 0.000000000000000, 1.000000000000000 }
};

// Definición del vector Bd_p (4x1) como un array de dobles
const double Bd[4] = {
    0.000000002919643, 
    0.000001167857143, 
    0.000050000000000, 
    0.010000000000000 
};


// ---------------------- Ganancias del observador ------------------------
double LdX[4] = {
    0.213822782856712,
    1.663008063736376,
    0.827026508279530,
    1.074469071926424
};



double LdY[4] = {0,0,0,0};



double Kp_dX[4] = { 1.294138049009179, 1.533540549035755, 4.179500908982886, 2.885880403273112 };
double Ki_dX = -0.080471508364484;



double Kp_dY[4] = { 0,0, 0,0 };
double Ki_dY = 0;



//SIMULACION TERMINADA.

float integX = 0.0;
float integY = 0.0;

//Seguidor SIN Observador

// Estados y variables internas
float x_hatX[4] = {0,0,0,0};
float x_hatY[4] = {0,0,0,0};
float eiX = 0, eiY = 0;


//-------------------------  FORMAS ------------------------------------
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

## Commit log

2026-09-16 Add README.md for Ball and Plate project
    Added comprehensive documentation for the Ball and Plate control systems project, including objectives, system architecture, control strategies, experimental results, and project highlights.
2026-09-16 Repository update, added documentation, videos, pictures, diagrams, electronics, cad
    [ArmYRed.SLDPRT, Arm_Motor.SLDPRT, BALLANDPLATE.fzz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]
